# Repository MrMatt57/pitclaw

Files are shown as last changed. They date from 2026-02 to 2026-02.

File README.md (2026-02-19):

# Pit Claw logo Pit Claw



Open-source BBQ temperature monitor and controller. Uses an ESP32-S3 with a 3.5" touchscreen to maintain precise smoker temperature via PID-controlled fan and optional servo damper. Reads Thermoworks-compatible thermistor probes. Includes a web interface (PWA) for remote monitoring from any phone or computer on Wi-Fi. Touchscreen works fully offline.

### Touchscreen Dashboard

Real-time temperature display on the 3.5" capacitive touchscreen. Works fully offline — no Wi-Fi required.

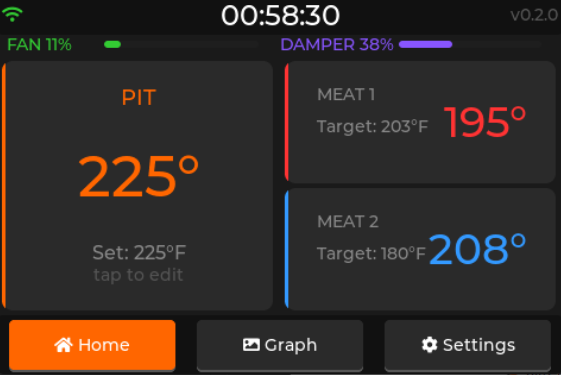
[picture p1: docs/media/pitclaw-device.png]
Pit Claw touchscreen dashboard


### Web Interface

Browser-based PWA with live temperature graph, predictive done-time curves, and full cook session control. Access from any device at `http://bbq.local`.

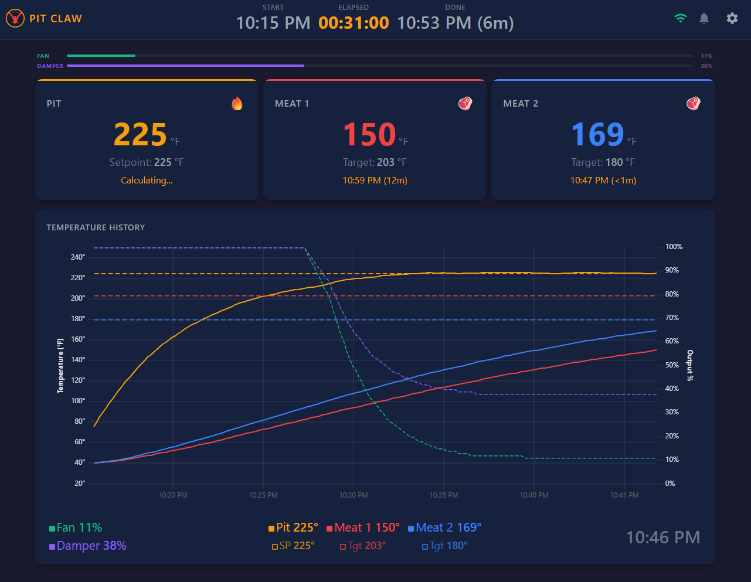
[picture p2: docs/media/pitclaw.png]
Pit Claw web UI with temperature history graph


## Features

- **3 probe inputs**: 1 pit (ambient) + 2 meat probes (Thermoworks Pro-Series compatible, 2.5mm jack)
- **PID temperature control**: Fan + optional damper hold pit temperature steady (±5°F typical)
- **3.5" capacitive touchscreen**: Real-time dashboard — works fully without Wi-Fi
- **Web UI (PWA)**: Install to home screen, real-time graph, set points, alarms, session export
- **Predictive curve**: Chart shows dashed projection from current meat temp to target with estimated done time
- **Alarms**: Local buzzer + browser audio + Pushover push notifications
- **Cook session logging**: Persists through power loss, download as CSV/JSON before starting next cook
- **Easy setup**: QR code on screen for Wi-Fi, captive portal, mDNS (`bbq.local`)
- **OTA updates**: Flash new firmware from the browser — no USB after initial setup
- **Error detection**: Probe disconnect/short, fire-out warning, Wi-Fi auto-reconnect
- **Calibration**: Per-probe Steinhart-Hart coefficients with offset adjustment
- **3D printable enclosure**: PETG case with snap-fit assembly

## Hardware

### Bill of Materials

All internal electronics mount on a single 50x70mm carrier perfboard behind the display. Requires basic soldering (~20 joints). Enclosure target is ~100x70x40mm.

| # | Component | Product | Qty | Price | Link |
|---|---|---|-----|---|---|
| 1 | MCU + Display | WT32-SC01 Plus (ESP32-S3, 3.5" 480x320 capacitive touch) | 1 | ~$20-25 | [Amazon](https://www.amazon.com/s?k=WT32-SC01+Plus) / AliExpress |
| 2 | ADC | ADS1115 16-bit I2C breakout (HiLetgo 3-pack) | 1 | ~$4 | [Amazon](https://www.amazon.com/s?k=ADS1115+16+bit) |
| 3 | Blower Fan | GDSTIME 5015 12V dual ball bearing blower (2-pack) | 1 | ~$10-12 | [Amazon](https://www.amazon.com/s?k=GDSTIME+5015+12V+blower) |
| 4 | MOSFET | IRLZ44N logic-level N-channel TO-220 (5-pack) | 1 | ~$7 | [Amazon](https://www.amazon.com/s?k=IRLZ44N+MOSFET) |
| 5 | Servo | Miuzei MG90S metal gear micro servo (2-pack) | 1 | ~$8-10 | [Amazon](https://www.amazon.com/s?k=MG90S+metal+gear+servo) |
| 6 | Power Supply | ALITOVE 12V 5A DC adapter (5.5x2.1mm barrel) | 1 | ~$10-12 | [Amazon](https://www.amazon.com/s?k=12V+5A+power+supply+barrel) |
| 7 | Buck Converter | MP1584EN mini adjustable DC-DC (6-pack, 22x17mm) | 1 | ~$8 | [Amazon](https://www.amazon.com/s?k=MP1584EN+buck+converter) |
| 8 | Power Jack | Panel-mount DC barrel jack 5.5x2.1mm (4-pack) | 1 | ~$6 | [Amazon](https://www.amazon.com/s?k=panel+mount+DC+barrel+jack+5.5x2.1) |
| 9 | Probe Jacks | CESS 2.5mm mono TS panel-mount with nut (4-pack) | 1 | ~$6-8 | [Amazon](https://www.amazon.com/s?k=2.5mm+mono+panel+mount+jack) |
| 10 | Buzzer | Piezo buzzer disc 3-5V (5-pack) | 1 | ~$5 | [Amazon](https://www.amazon.com/s?k=piezo+buzzer+disc+5V) |
| 11 | Carrier Board | 50x70mm perfboard (10-pack) | 1 | ~$6 | [Amazon](https://www.amazon.com/s?k=50x70mm+perfboard) |
| 12 | Resistors | 10K ohm 1% metal film (pack) | 3 | ~$5 | [Amazon](https://www.amazon.com/s?k=10K+1%25+metal+film+resistor) |
| 13 | Capacitors | 0.1uF ceramic (pack) | 3 | ~$5 | [Amazon](https://www.amazon.com/s?k=0.1uF+ceramic+capacitor) |
| 14 | Hookup Wire | 22AWG solid core (assorted colors) | 1 | ~$8 | [Amazon](https://www.amazon.com/s?k=22AWG+solid+core+hookup+wire) |
| | | **Total (excluding probes)** | | **~$95-115** | |

### Temperature Probes (buy separately)

Any Thermoworks Pro-Series probe with 2.5mm mono jack works:
- [TX-1003X-AP](https://www.thermoworks.com/tx-1003x-ap/) — Air/pit probe with grate clip (~$19)
- [TX-1001X-OP](https://www.thermoworks.com/tx-1001x-op/) — Cooking/meat probe (~$21)

Compatible alternatives: Maverick ET-72/73 replacement probes (different Steinhart-Hart coefficients), Inkbird, FireBoard probes.

### 3D Printed Parts

All parametric [OpenSCAD](https://openscad.org/) (free) source files in `enclosure/`. Pre-exported STLs in `enclosure/stl/` if you just want to print. See the [enclosure README](enclosure/README.md) for print settings and assembly instructions.

**Controller enclosure** (`bbq-case.scad`) — three parts:
- **Front bezel** — holds display, bezel lip frames the screen
- **Rear shell** — houses carrier board, panel-mount jacks, cable slots, ventilation
- **Kickstand** — detachable flip-out stand
- Target size: ~100 x 70 x 40mm
- Assembly: 4x M3x8mm screws

**Fan + damper assembly** (`bbq-fan-assembly.scad`) — two parts:
- **Blower housing** — holds 5015 fan, MG90S servo, butterfly damper plate
- **UDS pipe adapter** — friction-fits over 3/4" NPT pipe nipple, secured with hose clamp
- Airflow: outside air → damper → fan → duct → pipe adapter → drum
- The blower housing output is a standard round duct — future adapters for other smokers (WSM, kamado, offset) mate to the same interface

**Print settings** (both):
- Material: PETG (80°C glass transition, resists outdoor heat and grease)
- 4 walls, 30%+ infill, 0.2mm layers, no supports needed

**Additional hardware for assembly:**
- 4x M3x8mm screws + threaded inserts (controller case)
- 2x small hose clamps (fan assembly to pipe, adapter to pipe nipple)
- High-temp gasket tape (seal adapter to pipe nipple)

## Getting Started

### 1. Clone and Set Up

```bash
git clone https://github.com/MrMatt57/pitclaw.git
cd pitclaw
```

**Windows** — one script installs everything (Git, Python, PlatformIO CLI, OpenSCAD):

```powershell
# Run from an elevated (Admin) PowerShell
powershell -ExecutionPolicy Bypass -File scripts\setup-dev.ps1
```

**Other platforms** — install [PlatformIO CLI](https://docs.platformio.org/en/latest/core/installation.html) (`pip install platformio`).

### 2. Wire and Assemble

Solder the carrier board and wire everything up. See the [wiring guide](docs/wiring.md) for the full diagram and pin assignments.

### 3. Build and Flash

```bash
cd firmware

# Build firmware
pio run -e wt32_sc01_plus

# Connect WT32-SC01 Plus via USB-C, then flash
pio run -e wt32_sc01_plus --target upload

# Upload web UI files to flash filesystem
pio run -e wt32_sc01_plus --target uploadfs
```

After this initial flash, all future firmware updates can be done over Wi-Fi at `http://bbq.local/update`.

### 4. First Boot

1. Power on — the setup wizard starts on the touchscreen
2. Select temperature units (°F or °C)
3. Scan the QR code on screen with your phone to connect to the setup Wi-Fi
4. Enter your home Wi-Fi credentials in the portal page
5. Plug in probes — the wizard verifies live readings
6. Fan, servo, and buzzer do a quick self-test
7. Setup complete — dashboard appears

### 5. Use the Web UI

Open `http://bbq.local` in any browser on the same Wi-Fi network.

For the best experience, add it to your phone's home screen (it's a PWA):
- **iOS**: Safari → Share → Add to Home Screen
- **Android**: Chrome → Menu → Add to Home Screen

### Factory Reset

Hold your finger on the touchscreen for 10 seconds during the boot splash screen.

## Development

| Guide | Topics |
|---|---|
| [Firmware Development](docs/firmware-development.md) | Building, flashing, testing, architecture, configuration |
| [Web UI Development](docs/web-development.md) | Simulator, web UI editing, cook profiles, WebSocket protocol |
| [Wiring](docs/wiring.md) | Wiring diagram, pin assignments, carrier board layout |
| [Enclosure](enclosure/README.md) | 3D printing, assembly instructions, parametric customization |

## License

TBD

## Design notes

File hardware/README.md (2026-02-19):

# Hardware - KiCad Schematic

KiCad 8 project for the Pit Claw BBQ Controller carrier board circuit.

## Opening

1. Install [KiCad](https://www.kicad.org/) (free, open source)
2. Open `bbq-controller.kicad_pro`
3. The schematic editor opens `bbq-controller.kicad_sch`

## What's in the schematic

All components on the 50x70mm carrier board and their connections to the WT32-SC01 Plus:

| Ref | Component | Function |
|-----|---|---|
| U1 | MP1584EN module | 12V to 5V buck converter |
| U2 | ADS1115 module | 16-bit I2C ADC (3 probe channels) |
| Q1 | IRLZ44N | N-channel MOSFET fan driver |
| R1-R3 | 10K 1% | Probe voltage divider reference resistors |
| R4 | 10K | MOSFET gate pulldown |
| C1-C3 | 0.1uF | ADC input filter capacitors |
| BZ1 | Piezo buzzer | Audio alarm |
| J1 | Barrel jack | 12V DC power input |
| J2-J4 | 2.5mm mono jacks | Temperature probe connectors |
| J5 | 8-pin header | WT32-SC01 Plus extension connector |
| J6 | 3-pin header | MG90S servo (damper) |
| J7 | 2-pin header | 5015 blower fan |

## Net labels

Inter-section connections use net labels (matching labels are electrically connected):

| Net Label | Signal | From | To |
|---|---|---|-----|
| SDA | I2C data | U2 pin 3 | J5 pin 1 (GPIO10) |
| SCL | I2C clock | U2 pin 4 | J5 pin 2 (GPIO11) |
| FAN_PWM | Fan speed | Q1 gate / R4 | J5 pin 3 (GPIO12) |
| SERVO_SIG | Servo position | J6 pin 1 | J5 pin 4 (GPIO13) |
| BUZZER_SIG | Buzzer drive | BZ1 pin 1 | J5 pin 5 (GPIO14) |
| PROBE_PIT | Pit temp | R1/C1/J2 junction | U2 A0 (pin 7) |
| PROBE_MEAT1 | Meat 1 temp | R2/C2/J3 junction | U2 A1 (pin 8) |
| PROBE_MEAT2 | Meat 2 temp | R3/C3/J4 junction | U2 A2 (pin 9) |

## Exporting a viewable schematic

From KiCad's schematic editor:
- **PDF**: File > Export > PDF
- **SVG**: File > Export > SVG
- Place the exported file in `docs/` for easy reference

## Regenerating the schematic

The schematic is generated by `generate_schematic.py`. This script computes exact pin positions and wire endpoints so all connections are guaranteed to align.

```bash
python hardware/generate_schematic.py
```

To modify the schematic layout, edit component positions in the script and re-run. The script validates net label pairs on output.

## Notes

- Custom symbols (prefixed `bbq:`) are embedded in the schematic file -- no external symbol libraries needed
- The schematic uses standard KiCad power symbols (+12V, +5V, +3V3, GND)
- All wire endpoints are computed from pin definitions -- every connection is verified
- This is a carrier board schematic, not a PCB layout -- the board is hand-wired on perfboard

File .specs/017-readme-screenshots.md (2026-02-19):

# 017: Update README Screenshots

**Branch**: `feature/readme-screenshots`
**Created**: 2026-02-18

## Summary

Update the README to showcase both the hardware device and the web UI. Add a second screenshot for the embedded touchscreen device and update the existing web UI screenshot reference.

## Requirements

- Add a hardware/device screenshot placeholder in `docs/media/` (filename: `pitclaw-device.png`)
- Keep the existing web UI screenshot (`docs/media/pitclaw.png`) — user will replace the file with an updated version
- Update `README.md` to display both screenshots prominently near the top

## Design

Update the hero section of the README (after the badges, before Features) to show two screenshots side by side or stacked:
1. Hardware device photo (`pitclaw-device.png`) — placeholder file for now
2. Web UI screenshot (`pitclaw.png`) — existing file, user will update the actual image

Use a simple markdown table or inline images to display both.

## Files to Modify

| File | Change |
|---|---|
| `README.md` | Update screenshot section to show both device and web UI images |

## Test Plan

- [x] README renders correctly on GitHub with both image references
- [x] Placeholder filename `pitclaw-device.png` is referenced correctly
- [x] Existing `pitclaw.png` reference is preserved

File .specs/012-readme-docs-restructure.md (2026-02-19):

# 012: Restructure README and Documentation

**Branch**: `feature/readme-docs-restructure`
**Created**: 2026-02-18

## Summary

Restructure the README to focus on what new visitors need (what it is, hardware, quick start) and move developer-focused content into dedicated docs. The goal is a concise onboarding experience for people who want to build this project, with an index linking to deeper development guides.

## Requirements

- README should prominently show: what the project is, hardware requirements/BOM, and a quick getting started guide
- Move wiring diagram out of README into `docs/wiring.md`, linked from the hardware section
- Create `docs/firmware-development.md` covering firmware building, testing, architecture, and source layout
- Create `docs/web-development.md` covering simulator usage, cook profiles, web UI development, and WebSocket protocol
- README should have a "Development" section that serves as an index linking to the doc files
- Keep the README hardware section (BOM, probes, 3D printed parts) intact — builders need it
- Preserve all existing content; nothing should be lost, just reorganized
- All internal links should work correctly

## Design

### README.md (streamlined)

Keep these sections in README:
1. **Header** — logo, badge, one-paragraph description, screenshot
2. **Features** — bullet list (as-is)
3. **Hardware** — BOM table, probes, 3D printed parts. Add a link to `docs/wiring.md` for wiring details
4. **Quick Start** — condensed: clone, setup script, build & flash, first boot steps, accessing web UI, factory reset, OTA mention
5. **Development** — brief index paragraph linking to:
   - `docs/firmware-development.md` — building, testing, architecture
   - `docs/web-development.md` — web UI, simulator, WebSocket protocol
   - `docs/wiring.md` — wiring diagram and pin assignments
   - `enclosure/README.md` — 3D printing and assembly
6. **License** — TBD

Remove from README (moved to docs):
- Wiring diagram → `docs/wiring.md`
- Simulator section → `docs/web-development.md`
- Running Tests section → `docs/firmware-development.md`
- Web UI detailed description → `docs/web-development.md`

### docs/wiring.md

- Carrier board wiring diagram (the ASCII art from current README)
- Pin assignment table
- Probe voltage divider schematic

### docs/firmware-development.md

- Prerequisites (manual install list — the non-Windows path)
- Quick setup script mention
- Build & flash commands (firmware targets)
- Running tests (native + embedded)
- OTA update details
- Architecture overview: source layout tree, key modules described
- Configuration persistence (config.json structure)
- Error detection table
- Key technical constants (Steinhart-Hart, PID defaults, fan control)

### docs/web-development.md

- Simulator setup and usage (build, run, options)
- Cook profiles table
- Web UI features overview
- PWA details (manifest, service worker)
- WebSocket protocol documentation (all message types)
- Key constraint: web UI must work identically on simulator and ESP32
- Editing workflow (edit files in firmware/data/, refresh browser)

## Files to Modify

| File | Change |
|---|---|
| `README.md` | Restructure: keep intro/features/hardware/quick-start, add dev index, remove moved sections |
| `docs/wiring.md` | **New**: wiring diagram, pin assignments from README |
| `docs/firmware-development.md` | **New**: firmware dev guide with build/test/architecture content |
| `docs/web-development.md` | **New**: web UI + simulator dev guide |

## Test Plan

- [x] All links in README resolve correctly (relative paths to docs/)
- [x] No content lost — all information from old README exists somewhere in new structure
- [x] README is concise and focuses on builder onboarding
- [x] docs/wiring.md contains the full wiring diagram
- [x] docs/firmware-development.md covers building, testing, and architecture
- [x] docs/web-development.md covers simulator, web UI, and WebSocket protocol
- [ ] Firmware builds (`pio run -e wt32_sc01_plus`) — docs-only change, no source code modified
- [ ] Simulator builds (`pio run -e simulator`) — docs-only change, no source code modified

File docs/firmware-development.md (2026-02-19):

# Firmware Development

Guide for building, flashing, testing, and understanding the Pit Claw firmware.

## Prerequisites

### Quick Setup (Windows)

```powershell
# Run from an elevated (Admin) PowerShell in the repo root
powershell -ExecutionPolicy Bypass -File scripts\setup-dev.ps1
```

This installs Git, Python, Node.js, PlatformIO CLI, and OpenSCAD. The script is idempotent — safe to run again anytime.

### Manual Install

If you prefer to install tools yourself (or you're not on Windows):

1. [Git](https://git-scm.com/)
2. [Python 3.12+](https://www.python.org/)
3. [PlatformIO CLI](https://docs.platformio.org/en/latest/core/installation.html) — `pip install platformio`
4. [VS Code](https://code.visualstudio.com/) + [PlatformIO extension](https://platformio.org/install/ide?install=vscode) (recommended)

## Build Commands

All commands run from the `firmware/` directory.

```bash
# Build firmware
pio run -e wt32_sc01_plus

# Flash firmware via USB
pio run -e wt32_sc01_plus --target upload

# Upload web UI files to LittleFS
pio run -e wt32_sc01_plus --target uploadfs

# Build simulator (desktop, no hardware needed)
pio run -e simulator

# Clean build artifacts
pio run --target clean

# Serial monitor
pio device monitor --baud 115200
```

## Testing

```bash
# Desktop unit tests (PID, prediction, alarms — no hardware)
pio test -e native

# Single test suite
pio test -e native --filter test_desktop/test_pid

# On-device integration tests (requires connected hardware)
pio test -e wt32_sc01_plus
```

Tests use the Unity framework with two environments:
- **`native`** — runs on desktop, tests pure logic (PID, prediction, alarms, fan logic, temperature conversion)
- **`wt32_sc01_plus`** — runs on device, tests hardware integration (ADC, fan PWM, servo, buzzer, I2C)

## OTA Updates

After the initial USB flash, firmware can be updated over Wi-Fi:

1. Open `http://bbq.local/update` in a browser
2. Upload the `.bin` file from `.pio/build/wt32_sc01_plus/firmware.bin`
3. The device reboots with the new firmware

The LittleFS partition (config, session data, web UI files) is preserved across firmware updates.

## Architecture

### Source Layout

```
firmware/
  src/
    main.cpp                    # Setup + main loop (Arduino setup/loop pattern)
    config.h                    # Pin assignments, constants, defaults
    config_manager.h/.cpp       # Load/save config.json on LittleFS
    wifi_manager.h/.cpp         # WiFiManager captive portal, mDNS, auto-reconnect
    ota_manager.h/.cpp          # Web-based OTA firmware update endpoint
    pid_controller.h/.cpp       # PID wrapper (QuickPID + lid-open, startup, split-range)
    temp_manager.h/.cpp         # ADS1115 reading, Steinhart-Hart, EMA filtering
    temp_predictor.h/.cpp       # Rolling linear regression for done-time prediction
    fan_controller.h/.cpp       # PWM output with kick-start, long-pulse, min-speed
    servo_controller.h/.cpp     # Damper servo control
    alarm_manager.h/.cpp        # Threshold logic, hysteresis, buzzer + web triggers
    cook_session.h/.cpp         # Session state, circular buffer, LittleFS persistence
    error_manager.h/.cpp        # Probe disconnect/short, fan stall, fire-out detection
    web_protocol.h/.cpp         # Shared WebSocket protocol (message building/parsing)
    web_server.h/.cpp           # ESPAsyncWebServer, REST + WebSocket handlers
    split_range.h               # Fan + damper coordination from PID output
    units.h                     # Temperature unit conversion utilities
    display/
      ui_init.h/.cpp            # LVGL screen setup (dashboard, graph, settings)
      ui_update.h/.cpp          # Real-time widget updates
      ui_setup_wizard.h/.cpp    # First-boot setup wizard screens
      ui_colors.h               # Shared LVGL color constants
      graph_history.h/.cpp      # Adaptive-condensing graph history buffer
    simulator/                  # Desktop simulator (see web-development.md)
      sim_main.cpp              # SDL2 + mongoose main loop
      sim_thermal.h/.cpp        # Charcoal smoker physics simulation
      sim_profiles.h            # Pre-built cook profiles
      sim_web_server.h/.cpp     # Mongoose HTTP + WebSocket server
      mongoose.h/.c             # Mongoose embedded web server library
  data/                         # Web UI files (uploaded to LittleFS)
  test/
    test_desktop/               # Native tests
    test_embedded/              # On-device tests
  platformio.ini
```

### Key Modules

**PID Controller** (`pid_controller.h/.cpp`) — wraps QuickPID with BBQ-specific features: proportional-on-measurement, derivative-on-measurement, integral anti-windup conditioning. Includes lid-open detection (6% drop below setpoint) and startup mode.

**Temperature Manager** (`temp_manager.h/.cpp`) — reads ADS1115 ADC via I2C, converts raw ADC counts to temperature using Steinhart-Hart equation, applies EMA (exponential moving average) filtering, and supports per-probe calibration offsets.

**Fan + Damper Split-Range** (`split_range.h`) — the PID produces a single 0-100% output mapped to both actuators:
- Damper: linearly maps full PID range (0% = closed, 100% = open)
- Fan: activates above configurable threshold (default 30%), scales within its own min-max range
- Three modes: fan-only, fan+damper coordinated, damper-primary with fan boost

**Cook Session** (`cook_session.h/.cpp`) — stores the current cook as a circular buffer in RAM (600 samples, ~50 min at 5s intervals), flushed to LittleFS every 60 seconds for power-loss recovery. Only one session stored on device — web UI provides CSV/JSON download.

**Error Manager** (`error_manager.h/.cpp`) — detects probe disconnect (ADC max/open circuit), probe short (ADC zero), fire-out (pit declining >2°F/min for 10+ min at full fan), and Wi-Fi loss.

### Configuration

All user settings stored in `config.json` on LittleFS. Survives reboots and firmware OTA updates.

```json
{
  "wifi": { "ssid": "", "password": "" },
  "units": "F",
  "pid": { "p": 4.0, "i": 0.02, "d": 5.0 },
  "fan": { "mode": "fan_and_damper", "minSpeed": 15, "fanOnThreshold": 30 },
  "probes": {
    "pit":   { "name": "Pit",    "a": 7.3431401e-04, "b": 2.1574370e-04, "c": 9.5156860e-08, "offset": 0.0 },
    "meat1": { "name": "Meat 1", "a": 7.3431401e-04, "b": 2.1574370e-04, "c": 9.5156860e-08, "offset": 0.0 },
    "meat2": { "name": "Meat 2", "a": 7.3431401e-04, "b": 2.1574370e-04, "c": 9.5156860e-08, "offset": 0.0 }
  },
  "alarms": {
    "pitBand": 15,
    "pushover": { "enabled": false, "userKey": "", "apiToken": "" }
  },
  "setupComplete": false
}
```

### Technical Constants

**Thermoworks Pro-Series Steinhart-Hart Coefficients:**
- A = 7.3431401e-04, B = 2.1574370e-04, C = 9.5156860e-08
- Reference resistor: 10K ohm (1% metal film)
- 0.1uF ceramic filter cap on each ADC input

**PID Defaults (HeaterMeter-derived):**
- P = 4.0, I = 0.02, D = 5.0
- Temp sampling: 1s interval, 4-reading average
- PID compute: every 4 seconds
- Lid-open threshold: 6% drop below setpoint

**Fan Control:**
- PWM frequency: 25 kHz
- Kick-start: 75% for 500ms
- Long-pulse mode below 10% (10s cycle)
- Min sustained speed: 15%

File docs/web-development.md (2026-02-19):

# Web UI Development

Guide for developing the Pit Claw web interface and using the desktop simulator.

## Simulator

The simulator runs the LVGL touchscreen UI in an SDL2 window and serves the web UI via an embedded web server — no ESP32 hardware needed.

### Build and Run

```bash
cd firmware

# Build
pio run -e simulator

# Run (opens SDL2 window + web server at http://localhost:3000)
.pio/build/simulator/program
```

### Command-Line Options

```bash
.pio/build/simulator/program --speed 10         # 10x time acceleration
.pio/build/simulator/program --speed 50         # 50x speed (12-hour cook in ~15 min)
.pio/build/simulator/program --profile stall    # brisket stall scenario
.pio/build/simulator/program --port 8080        # custom web server port
```

### Cook Profiles

| Profile | Description | Duration (real time at 1x) |
|---|---|---|
| `normal` | 225°F pit, pork butt to 203°F, smooth rise | ~10 hours |
| `stall` | 225°F pit, brisket with 150-170°F stall plateau | ~14 hours |
| `hot-fast` | 300°F pit, chicken thighs to 185°F | ~2 hours |
| `temp-change` | Start at 225°F, bump to 275°F mid-cook | ~8 hours |
| `lid-open` | Normal cook with periodic lid-open temp drops | ~10 hours |
| `fire-out` | Normal cook, fire dies at 4 hours | ~6 hours |
| `probe-disconnect` | Normal cook, meat1 probe disconnects at 3 hours | ~10 hours |

### How It Works

- **SDL2 window** renders the LVGL touchscreen UI (same code as firmware)
- **Mongoose HTTP server** serves web UI files from `firmware/data/`
- **WebSocket** on the same port sends simulated data using the shared protocol (`web_protocol.cpp`)
- **Thermal model** (`sim_thermal.cpp`) simulates charcoal fire physics, heat decay, meat temp rise, and PID response

Both the touchscreen and web UI are driven by the same thermal model and shared WebSocket protocol — one source of truth.

### Editing the Web UI

Web UI files live in `firmware/data/`:

```
firmware/data/
  index.html          # Main page
  app.js              # Application logic
  style.css           # Styles
  manifest.json       # PWA manifest
  favicon.svg         # App icon
  sw.js               # Service worker (offline shell caching)
```

Edit these files and refresh your browser — no recompile needed. Only the simulator itself (C++ code) requires rebuilding.

**Key constraint:** The web UI code must work identically on both the simulator and the real ESP32. No simulator-specific code in the web UI — the abstraction boundary is the WebSocket protocol.

## Web UI Features

- **Live temperatures** — pit and both meat probes with set points
- **Temperature graph** — uPlot time-series chart with pit temp, meat temps, fan %, and damper %
- **Predictive curve** — dashed projection from current meat temp to target, with predicted done time
- **Controls** — set pit target temperature, meat target temperatures, alarm thresholds
- **Cook timer** — starts when pit reaches set point; tracks total cook time
- **Session export** — download cook data as CSV/JSON (device stores only current/last session)
- **OTA update** — flash new firmware at Settings → Update
- **Alarms** — configure pit deviation band, meat targets, Pushover notifications

### Graph

The timeline focuses on the active cook — ramp-up time is shown compressed on the left, with the main view starting from when the pit first reaches set temperature. The chart extends to the right with a dashed predictive curve showing the projected path to the meat target temperature, with the predicted done time displayed at the end. All times shown in the browser's local timezone.

### PWA

The web UI is a Progressive Web App:

- `manifest.json` defines the app name, icon, theme color, and `display: standalone`
- `sw.js` caches the app shell (HTML/JS/CSS) for offline loading — data still requires a WebSocket connection
- "Add to Home Screen" for a native-app experience on phones:
  - **iOS**: Safari → Share → Add to Home Screen
  - **Android**: Chrome → Menu → Add to Home Screen

## WebSocket Protocol

All communication between the web UI and device (or simulator) uses JSON over WebSocket.

### Server → Client

**Periodic data** (every 1-2 seconds):
```json
{
  "type": "data",
  "ts": 1707600000,
  "pit": 225.5,
  "meat1": 145.2,
  "meat2": 98.7,
  "fan": 45,
  "damper": 80,
  "sp": 225,
  "lid": false,
  "est": 1707614400,
  "meat1Target": 203,
  "meat2Target": null,
  "errors": []
}
```

**History dump** (on connect):
```json
{
  "type": "history",
  "sp": 225,
  "meat1Target": 203,
  "meat2Target": null,
  "data": [[ts, pit, meat1, meat2, fan, damper], ...]
}
```

**Session events:**
```json
{"type": "session", "action": "reset", "sp": 225}
{"type": "session", "action": "download", "format": "csv", "data": "timestamp,pit,meat1,...\n..."}
```

### Client → Server

```json
{"type": "set", "sp": 250}
{"type": "alarm", "meat1Target": 203, "meat2Target": 185, "pitBand": 15}
{"type": "session", "action": "new"}
{"type": "session", "action": "download", "format": "csv"}
```

### Timestamps

All timestamps from the ESP32 are UTC epoch seconds. The browser converts to local timezone for display. The chart library (uPlot) handles timezone-aware axis labels.

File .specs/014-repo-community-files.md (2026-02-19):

# 014: Repo Community Files

**Branch**: `feature/repo-community-files`
**Created**: 2026-02-18

## Summary

Add GitHub community files: Dependabot config, issue templates (bug report + feature request), PR template, and security policy. These were generated by the `/setup` command and need to be committed to the repo.

## Requirements

- Add `.github/dependabot.yml` — weekly updates for GitHub Actions and PlatformIO/pip
- Add `.github/ISSUE_TEMPLATE/bug_report.yml` — YAML form with description, repro steps, expected behavior, component dropdown, firmware version
- Add `.github/ISSUE_TEMPLATE/feature_request.yml` — YAML form with problem, proposed solution, alternatives, component dropdown
- Add `.github/ISSUE_TEMPLATE/config.yml` — disable blank issues
- Add `.github/PULL_REQUEST_TEMPLATE.md` — Summary + Test plan format matching /ship workflow
- Add `SECURITY.md` — responsible disclosure policy scoped to local-network IoT device

## Design

Straightforward file addition — all files already created by `/setup` command. Just need to be committed and pushed.

## Files to Modify

| File | Change |
|---|---|
| `.github/dependabot.yml` | Add — Dependabot config |
| `.github/ISSUE_TEMPLATE/bug_report.yml` | Add — Bug report template |
| `.github/ISSUE_TEMPLATE/feature_request.yml` | Add — Feature request template |
| `.github/ISSUE_TEMPLATE/config.yml` | Add — Disable blank issues |
| `.github/PULL_REQUEST_TEMPLATE.md` | Add — PR template |
| `SECURITY.md` | Add — Security policy |

## Test Plan

- [x] All 6 files exist with correct content
- [x] Issue templates use valid GitHub YAML form syntax
- [x] Dependabot config uses v2 format
- [x] PR template matches /ship workflow format (Summary + Test plan)
- [x] SECURITY.md links to correct repo for private vulnerability reporting

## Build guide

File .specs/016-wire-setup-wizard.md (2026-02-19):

# 016: Wire Setup Wizard into Boot Flow + Boot Splash

**Branch**: `feature/wire-setup-wizard`
**Created**: 2026-02-18

## Summary

The setup wizard UI is fully implemented (all 6 steps: Welcome, Units, Wi-Fi QR, Probe Check, Hardware Test, Done) but nothing in `main.cpp` or `sim_main.cpp` calls it. This feature wires the wizard into the boot flow so it runs on first boot (when `setupComplete == false`), adds a boot splash screen with a 10-second hold for factory reset, and adds a `--wizard` CLI flag to the simulator for testing the wizard flow in the SDL2 window.

## Requirements

- On startup, show a boot splash screen for 2 seconds with "Pit Claw" branding and version
- During boot splash, if user holds the touchscreen for 10 continuous seconds, trigger factory reset (wipe config, restart into wizard)
- Show a progress indicator during the hold so the user knows it's working
- After boot splash, check `configManager.isSetupComplete()`:
  - If `false` → launch the setup wizard
  - If `true` → load the dashboard (current behavior)
- Wire all wizard callbacks in `main.cpp`: units selection saves to configManager, hardware test buttons trigger fan/servo/buzzer, completion sets `setupComplete = true` and saves config
- After wizard's Done screen, automatically transition to the dashboard after a brief pause (2 seconds)
- During wizard, update probe readings on the probe-check screen from `tempManager` in the main loop
- Simulator: add `--wizard` flag to force-start the wizard (simulates first-boot)
- Simulator: wire wizard callbacks with simulator-local stubs (print messages for hardware test, update `g_is_fahrenheit` for units)
- Simulator: boot splash shown briefly (1 second) when `--wizard` is used, skipped otherwise

## Design

### Boot Splash Screen (`ui_boot_splash.h/.cpp`)

New LVGL module with a simple splash screen:
- Dark background (`COLOR_BG`)
- "Pit Claw" in large orange text centered
- Version string below in dim text
- Small hint at bottom: "Hold screen 10s for factory reset" in very dim text
- A thin progress bar (hidden by default) that fills over 10 seconds when the screen is pressed

Public API:
```cpp
void ui_boot_splash_init();                    // Create and show splash screen
bool ui_boot_splash_is_active();               // Still in splash phase?
void ui_boot_splash_update(bool pressed);      // Call each loop tick with touch state
bool ui_boot_splash_factory_reset_triggered(); // Was 10s hold completed?
float ui_boot_splash_hold_progress();          // 0.0-1.0 for progress bar
void ui_boot_splash_end();                     // Clean up splash, prepare for next screen
```

The splash screen handles its own timing internally:
- Tracks cumulative press duration (resets if released)
- After 2 seconds with no press, marks itself as done (`is_active` → false)
- If press reaches 10 seconds, sets factory_reset flag and marks done
- The 2-second auto-dismiss timer pauses while the screen is being pressed

### Main.cpp Boot Flow Changes

Add a boot phase state machine:
```cpp
enum class BootPhase { SPLASH, WIZARD, RUNNING };
static BootPhase g_bootPhase = BootPhase::SPLASH;
```

In `setup()`:
1. Init all hardware modules as today (steps 1-12 unchanged)
2. Call `ui_init()` (initializes LVGL, creates no screens yet — we'll show splash first)
3. Call `ui_boot_splash_init()` to show the splash screen
4. Do NOT set up dashboard callbacks yet

In `loop()`:
- **SPLASH phase**: Only run `ui_tick()` + `ui_handler()` + `ui_boot_splash_update()`. Check `ui_boot_splash_is_active()`. When done:
  - If factory reset triggered → call `configManager.factoryReset()` (which restarts)
  - If `!configManager.isSetupComplete()` → init wizard, wire wizard callbacks, switch to WIZARD phase
  - Else → init dashboard, wire dashboard callbacks, switch to RUNNING phase
- **WIZARD phase**: Run `ui_tick()` + `ui_handler()`. Update wizard probe readings at 1Hz. When `!ui_wizard_is_active()`:
  - Init dashboard, wire dashboard callbacks, switch to RUNNING phase
- **RUNNING phase**: Existing loop behavior (all module updates, display updates, etc.)

### Wizard Callbacks in main.cpp

```cpp
static void wiz_fan_test() {
    fanController.setSpeed(75);
    delay(500);
    fanController.setSpeed(0);
}
static void wiz_servo_test() {
    servoController.setPosition(100);
    delay(500);
    servoController.setPosition(0);
}
static void wiz_buzzer_test() {
    alarmManager.beepOnce();  // Need to verify this method exists, or use direct buzzer
}
static void wiz_units(bool isFahrenheit) {
    configManager.setUnits(isFahrenheit ? "F" : "C");
    tempManager.setUseFahrenheit(isFahrenheit);
}
static void wiz_complete() {
    configManager.setSetupComplete(true);
    configManager.save();
}
```

### Wizard → Dashboard Transition

After the wizard's Done screen (step 5), `cb_complete` fires immediately. But we want the "Setup Complete!" screen to show for ~2 seconds before transitioning to the dashboard. Two approaches:

**Chosen approach**: In the WIZARD phase of the main loop, after `ui_wizard_is_active()` returns false, start a 2-second timer. After the timer expires, initialize the dashboard and switch to RUNNING. This keeps the transition logic in main.cpp rather than in the wizard module.

### Simulator Changes (`sim_main.cpp`)

Add `--wizard` CLI flag:
```cpp
bool wizardMode = false;
// In arg parsing:
} else if (strcmp(argv[i], "--wizard") == 0) {
    wizardMode = true;
}
```

When `wizardMode` is true:
1. Show boot splash briefly (1 second delay with LVGL ticking)
2. Call `ui_wizard_init()` and `ui_wizard_set_callbacks()` with simulator stubs
3. In main loop, check `ui_wizard_is_active()` — when done, init dashboard and continue

Simulator wizard callbacks:
- Fan test: `printf("[SIM] Fan test\n")`
- Servo test: `printf("[SIM] Servo test\n")`
- Buzzer test: `printf("[SIM] Buzzer test\n")`
- Units: Update `g_is_fahrenheit` and call `ui_set_units()`
- Complete: Print message, no config save needed

When `wizardMode` is false: skip splash, go straight to dashboard as today.

Update `print_usage()` to list `--wizard` option.

### Existing Wizard Module — No Changes Needed

The wizard code in `ui_setup_wizard.cpp` is complete and doesn't need modification. The `cb_complete` callback + `wizard_active = false` behavior gives main.cpp everything it needs to detect completion and transition.

### Build Filter

The simulator build already includes `+<display/>` which will pick up the new `ui_boot_splash.cpp`. No `platformio.ini` changes needed.

## Files to Modify

| File | Change |
|---|---|
| `firmware/src/display/ui_boot_splash.h` | **NEW** — Boot splash screen header |
| `firmware/src/display/ui_boot_splash.cpp` | **NEW** — Boot splash screen with hold-to-reset logic |
| `firmware/src/main.cpp` | Add boot phase state machine, wire wizard callbacks, splash → wizard → dashboard flow |
| `firmware/src/simulator/sim_main.cpp` | Add `--wizard` flag, boot splash, wizard callback stubs, wizard → dashboard transition |

## Test Plan

- [ ] Simulator builds (`pio run -e simulator`)
- [ ] Simulator runs normally (no --wizard): skips splash, shows dashboard immediately
- [ ] Simulator with `--wizard`: shows boot splash briefly, then setup wizard with all 6 steps
- [ ] Wizard units step: tapping °F or °C advances and prints unit choice
- [ ] Wizard hardware test: tapping Fan/Servo/Buzzer buttons prints test messages
- [ ] Wizard Done step: shows "Setup Complete!" then auto-transitions to dashboard after ~2s
- [ ] After wizard completes, dashboard is fully functional (thermal sim runs, web UI serves)
- [ ] Firmware builds (`pio run -e wt32_sc01_plus`)
- [ ] Desktop tests pass (`pio test -e native`)

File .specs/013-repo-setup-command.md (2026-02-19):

# 013: Repo Setup Command

**Branch**: `feature/repo-setup-command`
**Created**: 2026-02-18

## Summary

Create a `/setup` Claude Code slash command that configures the GitHub repo with best practices for a solo developer. It audits current settings, shows a summary of proposed changes, asks for confirmation, then executes all configuration via `gh` CLI and file creation. Designed to be run once per repo.

## Requirements

- Create `.claude/commands/setup.md` as a Claude Code slash command
- The command must:
  1. Audit current repo state (branch protection, settings, labels, templates, etc.)
  2. Display a clear summary of what will be changed/created
  3. Ask user for confirmation before making any changes
  4. Execute all changes via `gh` API calls and file creation
  5. Report what was done
- Solo-dev-friendly: no required PR reviews, no team-oriented friction
- Idempotent where possible (safe to re-run, skips things already configured)

## Design

The command is a Claude Code slash command (`.claude/commands/setup.md`) with allowed tools for `gh` API calls, file creation, and bash commands. It runs interactively — Claude audits, presents a plan, confirms, then executes.

### What it configures:

#### 1. Branch Protection (update `main`)
- **Required status checks**: keep existing (`Firmware Build & Test`), enable strict (up-to-date before merge)
- **Required PR reviews**: remove (set to 0) — solo dev, no reviewer
- **Required linear history**: enable — enforces squash/rebase (matches squash-only setting)
- **Force pushes**: keep blocked
- **Branch deletion**: keep blocked
- **Enforce admins**: keep false — allows admin bypass in emergencies

#### 2. Repo Settings
- **Topics**: `esp32`, `esp32-s3`, `bbq`, `temperature-controller`, `pid-controller`, `smoker`, `iot`, `arduino`, `lvgl`, `platformio`, `pwm`
- **Vulnerability alerts**: enable

#### 3. Dependabot (`.github/dependabot.yml`)
- GitHub Actions: weekly updates
- PlatformIO/pip: weekly updates (pip ecosystem for PlatformIO)

#### 4. Issue Templates
- `.github/ISSUE_TEMPLATE/bug_report.yml` — YAML form: description, steps to reproduce, expected behavior, environment (firmware version, browser, etc.)
- `.github/ISSUE_TEMPLATE/feature_request.yml` — YAML form: problem, proposed solution, alternatives considered
- `.github/ISSUE_TEMPLATE/config.yml` — disable blank issues, link to discussions if enabled

#### 5. PR Template
- `.github/PULL_REQUEST_TEMPLATE.md` — Summary (bullet points) + Test Plan (checklist) format matching the `/ship` workflow

#### 6. Security Policy
- `SECURITY.md` — responsible disclosure policy, supported versions, contact info

#### 7. Project Labels
Add these project-specific labels (keep existing defaults):
| Label | Color | Description |
|---|---|---|
| `firmware` | `#1d76db` | ESP32 firmware code |
| `web-ui` | `#0e8a16` | Web UI (PWA) |
| `touchscreen` | `#5319e7` | LVGL touchscreen UI |
| `simulator` | `#fbca04` | Desktop simulator |
| `enclosure` | `#b60205` | 3D printed enclosure/hardware design |
| `hardware` | `#e99695` | Hardware, wiring, carrier board |
| `pid` | `#f9d0c4` | PID controller and tuning |
| `ci-cd` | `#c5def5` | CI/CD pipeline and automation |

### Command Flow

```
/setup

Claude:
1. Runs gh api calls to audit current state
2. Checks which files already exist
3. Presents summary:
   "Here's what I'll set up for your repo:

   Branch Protection:
   ✓ Required CI checks (already set)
   → Remove required PR reviews (currently 1)
   → Enable linear history

   Repo Settings:
   → Add topics: esp32, bbq, ...
   → Enable vulnerability alerts

   Files to Create:
   → .github/dependabot.yml
   → .github/ISSUE_TEMPLATE/bug_report.yml
   → .github/ISSUE_TEMPLATE/feature_request.yml
   → .github/ISSUE_TEMPLATE/config.yml
   → .github/PULL_REQUEST_TEMPLATE.md
   → SECURITY.md

   Labels to Add:
   → firmware, web-ui, touchscreen, simulator, enclosure, hardware, pid, ci-cd

   Proceed?"
4. On confirmation, executes everything
5. Reports results
```

## Files to Modify

| File | Change |
|---|---|
| `.claude/commands/setup.md` | Create — the slash command definition |
| `.claude/settings.json` | May need to add `Skill(setup)` to permissions if needed |

## Files Created by the Command (when run)

These files are NOT created during implementation — they are created when the `/setup` command is executed by the user:

| File | Purpose |
|---|---|
| `.github/dependabot.yml` | Dependabot configuration |
| `.github/ISSUE_TEMPLATE/bug_report.yml` | Bug report template |
| `.github/ISSUE_TEMPLATE/feature_request.yml` | Feature request template |
| `.github/ISSUE_TEMPLATE/config.yml` | Issue template config |
| `.github/PULL_REQUEST_TEMPLATE.md` | PR template |
| `SECURITY.md` | Security policy |

## Test Plan

- [x] `.claude/commands/setup.md` exists and is well-formed
- [x] Command includes `allowed-tools` frontmatter with necessary permissions (`Bash(gh *)`, `Write`, `Read`, `Glob`, `AskUserQuestion`)
- [x] Command audits current repo state before proposing changes
- [x] Command shows a clear summary of all proposed changes
- [x] Command asks for user confirmation before executing
- [x] Command handles already-configured items gracefully (skip or note as "already set")
- [x] All `gh` API calls in the command use correct endpoints and payloads
- [x] File templates (issue, PR, security, dependabot) follow GitHub's expected format
- [x] Labels use valid hex colors
- [x] Command is documented as one-time-use

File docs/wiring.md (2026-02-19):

# Wiring

All components on the carrier perfboard are connected with short soldered traces. External connections use wire runs to panel-mount jacks and the display board.

## Wiring Diagram

```
Panel-mount DC barrel jack (12V in)
  │
  └─► Carrier Board 12V rail
       ├─► MP1584EN buck converter IN → OUT (set to 5.0V)
       │     ├─► WT32-SC01 Plus 5V (via extension cable)
       │     └─► Servo VCC
       │
       ├─► IRLZ44N MOSFET drain
       │     └─► Fan +12V (fan GND to MOSFET source)
       │         Gate ◄── GPIO12 (with 10K pulldown to GND)
       │
       └─► GND rail (common ground)

WT32-SC01 Plus Extension Connector (8-pin ribbon cable)
  GPIO10 (SDA) ──► ADS1115 SDA (on carrier board)
  GPIO11 (SCL) ──► ADS1115 SCL (on carrier board)
  GPIO12       ──► IRLZ44N gate (on carrier board)
  GPIO13       ──► Servo signal (wire to servo)
  GPIO14       ──► Buzzer (on carrier board)
  3.3V         ──► ADS1115 VDD + voltage divider supply
  5V           ──► From MP1584EN output
  GND          ──► Common ground rail

Probe voltage dividers (on carrier board, x3)
  3.3V ──[10K 1% resistor]──┬──► ADS1115 AINx
                             │
                       [0.1uF cap]
                             │
    Panel-mount 2.5mm jack ──┴──► GND
    (tip=signal, sleeve=GND, polarity doesn't matter)
```

## Pin Assignments

| GPIO | Function |
|---|---|
| 10 | I2C SDA (ADS1115) |
| 11 | I2C SCL (ADS1115) |
| 12 | Fan PWM (via MOSFET) |
| 13 | Servo PWM |
| 14 | Buzzer |
| 21 | Spare |

## Carrier Board Layout (50x70mm)

```
┌──────────────────────────────────────────────────┐
│  MP1584EN        ADS1115 (socketed)              │
│  buck conv       ┌─────────┐                     │
│  ┌──────┐        │ A0 A1 A2│ A3(spare)           │
│  │12V→5V│        └─────────┘                     │
│  └──────┘                                        │
│                  R1  R2  R3   (10K 1% resistors)  │
│  IRLZ44N        C1  C2  C3   (0.1uF caps)       │
│  ┌──┐  10K                                       │
│  │FET│  pulldown  [BUZZER]                       │
│  └──┘                                            │
│                                                  │
│  Connectors: [12V in] [Fan] [Servo] [WT32 ext]  │
│              [Probe1] [Probe2] [Probe3]          │
└──────────────────────────────────────────────────┘
```

Components on the carrier board (~20 solder joints total):
- MP1584EN mini buck converter (12V→5V, 22x17mm module)
- ADS1115 breakout (pin-header socketed for replacement)
- IRLZ44N MOSFET (TO-220, logic-level, fully on at 3.3V for <1A loads) + 10K gate pulldown resistor
- 3x 10K 1% metal film resistors (voltage dividers)
- 3x 0.1uF ceramic capacitors (ADC input filters)
- Piezo buzzer (soldered directly)
- Power distribution traces (12V, 5V, 3.3V, GND rails)

Connections off the carrier board (short wire runs):
- 8-pin ribbon to WT32-SC01 Plus extension connector (2.0mm pitch, cable included with board)
- Wire pairs to panel-mount 2.5mm probe jacks (soldered to jack lugs)
- Wire pair to panel-mount DC barrel jack
- 2-pin to fan (JST-XH or direct solder)
- 3-pin to servo (standard servo connector)

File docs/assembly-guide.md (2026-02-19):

# Pit Claw BBQ Controller - Assembly Guide

Step-by-step instructions for building the Pit Claw temperature controller carrier board, wiring it to the WT32-SC01 Plus display, and assembling the enclosure.

## Safety

- **Soldering iron**: Work in a ventilated area. The iron tip is 300-400C. Use a stand and keep the tip away from skin, clothing, and plastic.
- **Lead-free solder recommended**: Wash hands after soldering.
- **12V power**: The barrel jack input is low-voltage DC (12V, ~2A max). No mains voltage is involved, but avoid shorting 12V to 3.3V components.
- **ESD awareness**: The ESP32-S3 and ADS1115 are sensitive to static. Touch a grounded metal surface before handling bare PCBs.

## Tools Required

| Tool | Notes |
|---|---|
| Soldering iron (adjustable temp) | 300-350C for through-hole, 230C for heat-set inserts |
| Solder (0.8mm rosin core) | Lead-free recommended |
| Wire strippers | For 22-26 AWG hookup wire |
| Flush cutters | Trimming leads and wire |
| Multimeter | Voltage and continuity testing (essential) |
| Screwdrivers (Phillips #1, #0) | M3 and M2 screws |
| Helping hands / PCB holder | Makes perfboard work much easier |
| Heat-shrink tubing + heat gun | Insulating solder joints on wire runs |
| Hot glue gun (optional) | Strain relief for wires |
| 22-26 AWG stranded hookup wire | Red, black, and 2-3 signal colors. ~1m of each |

## Bill of Materials

### Carrier Board Components

| Ref | Qty | Component | Specs | Notes |
|-----|-----|---|---|---|
| U1 | 1 | MP1584EN buck converter module | 22x17mm, adj output | Set to 5.0V with trimpot before installing |
| U2 | 1 | ADS1115 breakout board | 16-bit I2C ADC | Socket it (use pin headers) for easy replacement |
| Q1 | 1 | IRLZ44N N-channel MOSFET | TO-220, logic-level | Fully on at 3.3V gate drive |
| R1-R3 | 3 | 10K resistor (1% metal film) | 1/4W, axial | Probe voltage dividers |
| R4 | 1 | 10K resistor | 1/4W, axial | MOSFET gate pulldown |
| C1-C3 | 3 | 0.1uF ceramic capacitor | Axial or radial | ADC input noise filters |
| BZ1 | 1 | Piezo buzzer | 5V passive or active | Soldered directly to board |
| - | 1 | 50x70mm perfboard | 2.54mm pitch, double-sided | The carrier board itself |
| - | 2 | Pin header strips (female) | 2.54mm, for ADS1115 socket | Cut to length for the ADS1115 breakout |
| - | 1 | 8-pin connector / header | 2.0mm pitch | Mates with WT32-SC01 Plus extension connector |

### Panel-Mount Connectors

| Qty | Component | Notes |
|-----|---|---|
| 3 | 2.5mm mono panel-mount jacks | Thermoworks probe connectors (tip + sleeve) |
| 1 | DC barrel jack (panel-mount) | 5.5x2.1mm, 12V input |

### External Components

| Qty | Component | Notes |
|-----|---|---|
| 1 | WT32-SC01 Plus | ESP32-S3 with 3.5" 480x320 capacitive touchscreen |
| 1 | 5015 12V blower fan | 50x50x15mm centrifugal blower |
| 1 | MG90S servo | Standard micro servo for damper control |
| 1-3 | Thermoworks Pro-Series probes | NTC thermistor, 2.5mm mono plug |
| 1 | 12V DC power supply | 2A minimum, barrel plug 5.5x2.1mm |
| 1 | 8-pin ribbon cable (2.0mm) | Included with WT32-SC01 Plus board |

### Enclosure Hardware

| Qty | Component | Notes |
|-----|---|---|
| 4 | M3x8mm screws | Join bezel to rear shell |
| 4 | M3 heat-set threaded inserts | Optional (screws self-tap into PETG) |
| 4 | M3x6mm screws | Mount WT32-SC01 Plus to bezel standoffs |
| 4 | M3x6mm screws | Mount carrier board to shell standoffs (optional) |

---

## Schematic

The full circuit schematic is in KiCad format: [`hardware/bbq-controller.kicad_sch`](../hardware/bbq-controller.kicad_sch)

**To view/edit:** Open the `.kicad_pro` file in [KiCad](https://www.kicad.org/) (free, open source, industry standard EDA). You can export to PDF or SVG from KiCad via File > Export.

The circuit has five functional sections:

1. **Power supply** - 12V barrel jack through MP1584EN buck converter to 5V rail
2. **Probe voltage dividers** - 3x identical circuits: 3.3V -> 10K resistor -> junction -> NTC probe -> GND, with 0.1uF filter cap at each junction
3. **ADS1115 ADC** - Reads the three probe voltage divider junctions on A0-A2, communicates to ESP32 via I2C
4. **Fan driver** - IRLZ44N MOSFET switches 12V to the blower fan, gate driven by GPIO12 PWM with 10K pulldown
5. **Servo & buzzer** - Direct GPIO connections (GPIO13 servo signal, GPIO14 buzzer)

### Simplified Circuit Diagram

```
                           3.3V (from WT32)
                             |
                     ┌───────┼───────┐
                     |       |       |
                   [10K]   [10K]   [10K]    R1, R2, R3
                     |       |       |
              ┌──────┤───────┤───────┤
              |      |       |       |
            [0.1uF] [0.1uF] [0.1uF]        C1, C2, C3
              |      |       |       |
             GND    GND     GND     |
                     |       |       |
                    NTC     NTC     NTC     Probe thermistors
                     |       |       |      (via 2.5mm jacks)
                    GND     GND     GND

              A0─────┘   A1─┘   A2──┘
              ┌──────────────────────┐
              |      ADS1115        |
              |   (I2C: 0x48)       |
              └──┬───────┬──────────┘
                SDA     SCL
                 |       |
              GPIO10  GPIO11        WT32-SC01 Plus

  12V ────┬──[MP1584EN]──── 5V ────── WT32 5V pin
          |                           Servo VCC
          |
          ├──── Fan (+)
          |       |
          |     Fan (-)
          |       |
          |    Drain
          |   ┌──┤ IRLZ44N (Q1)
          |   |  Gate──────── GPIO12
          |   |  |
          |  [10K] R4 (pulldown)
          |   |  |
          |  GND Source
          |       |
          └──────GND

  GPIO13 ──── Servo Signal (orange wire)
  GPIO14 ──── Buzzer (+)
  GND    ──── Buzzer (-), Servo GND (brown wire)
```

---

## Perfboard Layout

The carrier board is a **50x70mm perfboard** (2.54mm hole pitch). The layout below shows where each component goes on the **front** (component side) of the board. The grid uses column letters (A-S, left to right) and row numbers (1-27, top to bottom).

### Component Placement Map (Front View)

```
            50mm (19 columns)
     A  B  C  D  E  F  G  H  I  J  K  L  M  N  O  P  Q  R  S
     ┌──────────────────────────────────────────────────────────┐
  1  │  .  .  .  .  .  .  .  .  .  .  .  .  .  .  .  .  .  .  │
  2  │  .  .  .  .  .  .  .  .  .  .  .  .  .  .  .  .  .  .  │
  3  │  . ┌──────────────┐ .  .  .  .  .  .  .  .  .  .  .  . │
  4  │  . │  MP1584EN    │ .  .  .  .  .  .  .  .  .  .  .  . │  70mm
  5  │  . │  buck conv   │ .  .  .  .  .  .  .  .  .  .  .  . │  (27
  6  │  . │  U1          │ .  .  .  .  .  .  .  .  .  .  .  . │  rows)
  7  │  . └──IN+ IN- OUT+ OUT-  .  .  .  .  .  .  .  .  .  . │
  8  │  .  .  .  .  .  .  .  .  .  .  .  .  .  .  .  .  .  .  │
  9  │  .  .  .  .  .  .  .  .  . ┌──────────────────┐  .  .  │
 10  │  .  .  .  .  .  .  .  .  . │  ADS1115 breakout│  .  .  │
 11  │  .  .  .  .  .  .  .  .  . │  U2 (socketed)   │  .  .  │
 12  │  .  .  .  .  .  .  .  .  . │  VDD GND SDA SCL │  .  .  │
 13  │  .  .  .  .  .  .  .  .  . │  A0  A1  A2  A3  │  .  .  │
 14  │  .  .  .  .  .  .  .  .  . └──────────────────┘  .  .  │
 15  │  .  .  .  .  .  .  .  .  .  R1   R2   R3  .  .  .  .  │
 16  │  .  .  .  .  .  .  .  .  .  │    │    │   .  .  .  .  │
 17  │  .  .  .  .  .  .  .  .  .  C1   C2   C3  .  .  .  .  │
 18  │  Q1 ┌──┐ .  .  .  .  .  .  .  .  .  .  .  . [BZ1]  . │
 19  │  G──│FET│──D  .  .  .  .  .  .  .  .  .  .  . buzzer . │
 20  │  │  └──┘  │  .  .  .  .  .  .  .  .  .  .  .  .  .  . │
 21  │  R4  S    │  .  .  .  .  .  .  .  .  .  .  .  .  .  . │
 22  │  │   │    │  .  .  .  .  .  .  .  .  .  .  .  .  .  . │
 23  │  .  .  .  .  .  .  .  .  .  .  .  .  .  .  .  .  .  .  │
 24  │  12V FAN  FAN SVO SVO SVO  .  .  PRB1 PRB1 PRB2 PRB2 PRB3│
 25  │  (+) (+)  (-) SIG VCC GND .  .  TIP  SLV  TIP  SLV  TIP │
 26  │  GND .    .   .   .   .   .  .  .    .    .    .    SLV │
 27  │  . ── WT32 8-pin ribbon cable pads ──  .  .  .  .  .  . │
     └──────────────────────────────────────────────────────────┘
          ▲ BOTTOM EDGE (faces rear shell panel-mount holes) ▲
```

### Component Reference

| Grid Position | Component | Notes |
|---|---|---|
| B3-G7 | U1 (MP1584EN) | Module pins: B7=IN+, D7=IN-, E7=OUT+, G7=OUT- |
| J9-Q14 | U2 (ADS1115) | Socketed in female pin headers. Check your breakout's pinout! |
| J15-J17 | R1 + C1 | Pit probe divider (connects to ADS1115 A0) |
| L15-L17 | R2 + C2 | Meat 1 probe divider (connects to ADS1115 A1) |
| N15-N17 | R3 + C3 | Meat 2 probe divider (connects to ADS1115 A2) |
| A18-C22 | Q1 (IRLZ44N) | TO-220, A19=Gate, B18-B20=body, C19=Drain |
| A21-A22 | R4 (10K) | Gate pulldown: Gate to GND |
| P18-P19 | BZ1 (Buzzer) | (+) up toward GPIO14 pad, (-) down to GND |
| A24-A26 | 12V + GND | Barrel jack wires solder here |
| B24-C24 | Fan + / Fan - | Fan connector pads |
| D24-F24 | Servo | Signal, VCC (5V), GND pads |
| I24-S26 | Probe jacks | Tip and Sleeve wire pads for each jack |
| A27-H27 | WT32 ribbon | 8-pin pads for ribbon cable to WT32-SC01 Plus |

### Wiring on the Back (Solder Side)

All connections are made on the **back of the perfboard** using short wire jumpers or solder bridges. Here are the key traces to run:

**Power rails** (run these first):
1. **GND bus** — horizontal trace along row 23, connecting: U1 OUT-, Q1 Source, R4 bottom, all cap bottoms (C1-C3), buzzer (-), all probe jack sleeves, J5 pin 8
2. **12V trace** — from barrel jack pad (A24) to U1 IN+ (B7), and to fan (+) pad (B24)
3. **5V trace** — from U1 OUT+ (E7) to servo VCC pad (E24), and to J5 pin 7
4. **3.3V bus** — from J5 pin 6 to: top of R1 (J15), top of R2 (L15), top of R3 (N15), and ADS1115 VDD

**Signal traces:**
5. **Probe junctions** — bottom of R1/top of C1 → ADS1115 A0, and → Probe 1 tip pad. Same for R2→A1→Probe 2, R3→A2→Probe 3
6. **I2C** — ADS1115 SDA → J5 pin 1 (GPIO10). ADS1115 SCL → J5 pin 2 (GPIO11)
7. **Fan PWM** — J5 pin 3 (GPIO12) → Q1 Gate (A19). Also R4 from Gate to GND
8. **Servo signal** — J5 pin 4 (GPIO13) → Servo signal pad (D24)
9. **Buzzer signal** — J5 pin 5 (GPIO14) → Buzzer (+) pad (P18)
10. **ADS1115 ADDR** — ADS1115 ADDR pin → GND bus (sets I2C address 0x48)

> Photo placeholder
> *Photo: Perfboard with components laid out before soldering (dry fit)*

> Photo placeholder
> *Photo: Back of perfboard showing all solder traces and wire jumpers*

### Tips for Perfboard Wiring

- **Plan before soldering.** Lay out all components in their positions first (dry fit). Use the grid map above as reference.
- **Solder power rails first.** GND bus → 12V → 5V → 3.3V. Test each rail before moving to signals.
- **Use colored wire.** Red for power, black for GND, and distinct colors for signal traces (e.g., blue for I2C, green for PWM).
- **Keep traces short.** Route wires on the back side along rows/columns. Avoid diagonal runs.
- **Socket the ADS1115.** Use female pin headers so you can remove the breakout board for debugging or replacement.
- **Check orientation.** MOSFET Q1 has Gate-Drain-Source left to right when facing the label. Verify your specific ADS1115 breakout's pinout — they vary between manufacturers.
- **Test as you go.** After each phase, use a multimeter to verify connections match the wiring list above.

---

## Assembly Instructions

### Overview

The build has 8 phases. Each phase ends with a checkpoint you can verify with a multimeter before moving on. This catches wiring mistakes early when they're easy to fix.

```
Phase 1: Power section (buck converter)
Phase 2: Probe voltage dividers (resistors + caps)
Phase 3: ADS1115 socket
Phase 4: Fan driver (MOSFET circuit)
Phase 5: Buzzer + connectors
Phase 6: Panel-mount components
Phase 7: Wiring harness (ribbon cable + external connections)
Phase 8: Enclosure assembly + final test
```

---

### Phase 1: Power Section

**Goal**: Mount the MP1584EN buck converter module and establish the 12V input and 5V output rails on the perfboard.

> **Before you begin**: Connect 12V to the MP1584EN module **off the perfboard** and adjust the trimpot with a small screwdriver until the output reads **5.0V** on your multimeter. This prevents accidental over-voltage to the ESP32.

#### Steps

1. **Plan your layout.** Place the MP1584EN module in the upper-left area of the 50x70mm perfboard. The module is 22x17mm and has 4 pins (IN+, IN-, OUT+, OUT-). Leave room to the right for the ADS1115 and voltage dividers.

   > Photo placeholder
   > *Photo: Perfboard with component placement marked (use a marker or tape to outline positions)*

2. **Solder the MP1584EN module.** Insert the 4 pins through the perfboard and solder from the back side. The module should sit flush against the board.

   > Photo placeholder
   > *Photo: MP1584EN soldered to perfboard, showing pin positions*

3. **Create power rails.** Using bare wire or solder bridges on the back of the perfboard:
   - Run a **12V trace** (red wire) from the MP1584EN IN+ pad toward the board edge where the barrel jack wires will connect. Also extend it toward the fan driver area (lower-left).
   - Run a **5V trace** (orange wire) from the MP1584EN OUT+ pad toward the right side of the board (where the WT32 and servo connections will go).
   - Run a **GND trace** (black wire) across the bottom of the board, connecting MP1584EN IN- and OUT- together. This is your common ground rail.

   > Photo placeholder
   > *Photo: Back of perfboard showing power rail traces/wires*

4. **Solder barrel jack wires.** Solder two ~10cm wires to the perfboard power input pads:
   - Red wire for 12V (will connect to barrel jack tip/center pin)
   - Black wire for GND (will connect to barrel jack sleeve)
   - Leave the other ends free for now; they'll connect to the panel-mount barrel jack in Phase 6.

#### Checkpoint 1

- [ ] With the barrel jack wires temporarily connected to a 12V supply, measure:
  - 12V between the IN+ pad and GND: **~12V**
  - 5V between the OUT+ pad and GND: **5.0V** (within 4.9-5.1V)
- [ ] Disconnect power before proceeding.

---

### Phase 2: Probe Voltage Dividers

**Goal**: Install the three 10K reference resistors and 0.1uF filter capacitors that form the voltage divider circuits for the temperature probes.

#### How the Probe Circuit Works

Each probe is an NTC (negative temperature coefficient) thermistor. It forms a voltage divider with a fixed 10K resistor:

```
3.3V ──[10K resistor]──┬──[NTC probe]── GND
                        |
                     ADC input
                        |
                     [0.1uF]
                        |
                       GND
```

The ADS1115 reads the voltage at the junction. As the probe heats up, its resistance drops, and the voltage at the junction changes. The firmware converts this voltage to temperature using the Steinhart-Hart equation.

#### Steps

1. **Install R1, R2, R3 (10K 1% resistors).** Place three 10K metal film resistors vertically in a row on the perfboard, to the right of the buck converter. Space them about 10mm apart. One lead of each connects to a 3.3V rail trace; the other lead goes to the junction point.

   > Photo placeholder
   > *Photo: Three 10K resistors installed on perfboard*

2. **Install C1, C2, C3 (0.1uF capacitors).** Place each capacitor near its corresponding resistor. One lead connects to the same junction point as the resistor; the other lead connects to the GND rail.

   > Photo placeholder
   > *Photo: Filter capacitors installed next to resistors*

3. **Create junction traces.** On the back of the perfboard, solder short traces or wire jumpers connecting each resistor-capacitor junction to a pad that will later wire to the ADS1115 analog input (A0, A1, A2).

4. **Run probe jack wires.** From each junction, also run a trace/pad for the wire that will go to the panel-mount 2.5mm probe jack. The other side of the probe jack connects to GND.

   > Photo placeholder
   > *Photo: Back of board showing voltage divider wiring*

5. **Create a 3.3V bus.** Run a trace connecting the top of all three 10K resistors together. This 3.3V bus will later connect to the WT32-SC01 Plus 3.3V output.

   > Photo placeholder
   > *Photo: 3.3V bus trace connecting all three dividers*

#### Checkpoint 2

- [ ] Continuity test: Each resistor's top lead connects to the 3.3V bus (all three should be connected together).
- [ ] Continuity test: Each capacitor's bottom lead connects to the GND rail.
- [ ] Each junction point (resistor bottom + cap top) is **isolated** from the other two junctions (no shorts between A0, A1, A2 points).
- [ ] Resistance from each junction to GND: **approximately 10K ohms** (reading through the resistor to the 3.3V bus, which is floating).

---

### Phase 3: ADS1115 Socket

**Goal**: Install female pin headers as a socket so the ADS1115 breakout can be inserted and removed without desoldering.

#### Steps

1. **Cut female pin headers.** The ADS1115 breakout board typically has 10 pins (some boards vary). Cut your female header strips to match your specific ADS1115 breakout board's pin layout.

   > Photo placeholder
   > *Photo: Female pin headers cut to size next to ADS1115 breakout*

2. **Position the socket.** Place the headers on the perfboard to the right of the voltage dividers. Insert the ADS1115 breakout into the headers to verify alignment, then remove the breakout and solder the headers.

   > Photo placeholder
   > *Photo: Female header socket soldered to perfboard*

3. **Wire the ADS1115 connections.** On the back of the perfboard, solder wires/traces from the socket pins to:

   | ADS1115 Pin | Connects To |
   |-------------|-------------|
   | VDD | 3.3V bus (same as probe resistors) |
   | GND | GND rail |
   | SDA | Pad for I2C SDA wire (to GPIO10) |
   | SCL | Pad for I2C SCL wire (to GPIO11) |
   | A0 | Probe 1 (Pit) junction |
   | A1 | Probe 2 (Meat 1) junction |
   | A2 | Probe 3 (Meat 2) junction |
   | A3 | Leave unconnected (spare) |
   | ADDR | Connect to GND (sets I2C address 0x48) |

   > Photo placeholder
   > *Photo: Back of board showing ADS1115 socket wiring*

4. **Insert the ADS1115 breakout.** Gently press the breakout board into the socket. It should seat firmly but be removable.

   > Photo placeholder
   > *Photo: ADS1115 breakout seated in socket*

#### Checkpoint 3

- [ ] ADS1115 VDD pin has continuity to the 3.3V bus.
- [ ] ADS1115 GND pin has continuity to the GND rail.
- [ ] ADS1115 ADDR pin has continuity to GND.
- [ ] A0, A1, A2 each have continuity to their respective probe junction points (and NOT to each other).
- [ ] SDA and SCL pads are isolated (no continuity between them).

---

### Phase 4: Fan Driver (MOSFET Circuit)

**Goal**: Install the IRLZ44N MOSFET and gate pulldown resistor to switch the 12V blower fan via PWM from GPIO12.

#### How the Fan Driver Works

```
        12V
         |
      Fan (+)
         |
      Fan (-)
         |
       Drain
     ┌───┤
     |   | IRLZ44N
     |  Gate ──── GPIO12 (PWM)
     |   |
    [10K] R4 (gate pulldown)
     |   |
    GND Source
          |
         GND
```

The MOSFET acts as a switch. When GPIO12 goes high (3.3V), the MOSFET turns on and current flows through the fan. The 10K pulldown resistor ensures the gate stays low (fan off) when GPIO12 is not actively driving it (e.g., during boot).

#### Steps

1. **Install Q1 (IRLZ44N MOSFET).** The IRLZ44N is in a TO-220 package with three legs: Gate, Drain, Source (left to right, facing the label). Place it in the lower-left area of the perfboard with the metal tab facing the board edge (for heat dissipation).

   > Photo placeholder
   > *Photo: IRLZ44N positioned on perfboard, pin labels visible*

2. **Solder the MOSFET pins.** Solder all three legs from the back. The pins are:
   - **Gate** (left): Will connect to GPIO12 via signal wire
   - **Drain** (center): Will connect to the fan's negative wire
   - **Source** (right): Connects to GND rail

3. **Install R4 (10K gate pulldown resistor).** Solder a 10K resistor between the Gate pin and GND. This keeps the gate pulled low when GPIO12 is floating (during ESP32 boot).

   > Photo placeholder
   > *Photo: 10K resistor connecting MOSFET gate to GND*

4. **Wire the Source to GND.** Connect the Source pin to the GND rail with a trace or wire on the back of the board.

5. **Wire the Drain.** Connect the Drain pin to a pad where the fan's negative wire will attach. Also run a trace from a nearby pad to the 12V rail for the fan's positive wire.

6. **Create fan connection pads.** Create two pads near the board edge for the fan wires:
   - Fan (+): Connected to 12V rail
   - Fan (-): Connected to MOSFET Drain

   > Photo placeholder
   > *Photo: Fan connection pads on perfboard edge*

7. **Wire the Gate signal.** Run a wire/trace from the Gate to a pad that will connect to GPIO12 through the ribbon cable.

#### Checkpoint 4

- [ ] MOSFET Source to GND: **continuity** (0 ohms).
- [ ] MOSFET Gate to GND: **~10K ohms** (through the pulldown resistor).
- [ ] MOSFET Drain to GND: **no continuity** (MOSFET is off; should read open/very high resistance).
- [ ] Fan (+) pad to 12V rail: **continuity**.
- [ ] Gate pad is isolated from Drain and Source (no accidental shorts).

---

### Phase 5: Buzzer and Remaining Connections

**Goal**: Install the piezo buzzer and create all remaining connection pads for the ribbon cable.

#### Steps

1. **Install BZ1 (piezo buzzer).** Solder the buzzer to the perfboard. Note the polarity:
   - **Positive (+)**: Connects to a pad for GPIO14
   - **Negative (-)**: Connects to GND rail

   > Photo placeholder
   > *Photo: Piezo buzzer soldered to perfboard*

2. **Create servo connection pads.** The servo has three wires:
   - **Orange** (signal): Pad for GPIO13
   - **Red** (VCC): Pad connected to 5V rail
   - **Brown** (GND): Pad connected to GND rail

   > Photo placeholder
   > *Photo: Servo connection pads labeled on perfboard*

3. **Create the ribbon cable header.** Create a row of pads (or solder a pin header) for the 8-pin ribbon cable connection. The pin mapping is:

   | Ribbon Pin | Signal | Perfboard Connection |
   |------------|--------|---------------------|
   | 1 | GPIO10 (SDA) | ADS1115 SDA pad |
   | 2 | GPIO11 (SCL) | ADS1115 SCL pad |
   | 3 | GPIO12 (Fan PWM) | MOSFET Gate pad |
   | 4 | GPIO13 (Servo PWM) | Servo signal pad |
   | 5 | GPIO14 (Buzzer) | Buzzer (+) pad |
   | 6 | 3.3V | 3.3V bus (probe dividers) |
   | 7 | 5V | 5V rail (from buck converter) |
   | 8 | GND | GND rail |

   > Photo placeholder
   > *Photo: Ribbon cable header/pads on perfboard edge*

4. **Final perfboard wiring.** Verify all traces on the back of the board connect correctly. Use your multimeter to check every connection in the table above.

   > Photo placeholder
   > *Photo: Complete back of perfboard showing all traces and wiring*

   > Photo placeholder
   > *Photo: Complete front of perfboard with all components installed*

#### Checkpoint 5

- [ ] Buzzer (+) to GPIO14 pad: **continuity**.
- [ ] Buzzer (-) to GND rail: **continuity**.
- [ ] Servo signal pad to GPIO13 pad: **continuity**.
- [ ] Servo VCC pad to 5V rail: **continuity**.
- [ ] Every ribbon cable pad connects to its intended destination and nothing else.
- [ ] **Full board continuity audit** - check for shorts between:
  - 12V and GND: **no continuity**
  - 5V and GND: **no continuity**
  - 3.3V and GND: **no continuity**
  - 12V and 5V: **no continuity**
  - All signal lines isolated from each other

---

### Phase 6: Panel-Mount Components

**Goal**: Install the probe jacks and barrel jack into the 3D-printed enclosure rear shell, and wire them to the carrier board.

#### Steps

1. **Thread the 2.5mm probe jacks.** Insert the three 2.5mm mono panel-mount jacks through the probe holes in the rear shell bottom edge. Secure each with its mounting nut from inside.

   > Photo placeholder
   > *Photo: Three probe jacks installed in rear shell, viewed from outside*

2. **Thread the DC barrel jack.** Insert the panel-mount barrel jack through its hole on the rear shell. Secure with its mounting nut.

   > Photo placeholder
   > *Photo: Barrel jack installed in rear shell*

3. **Wire the probe jacks.** For each 2.5mm mono jack, solder two wires (~8cm each):
   - **Tip lug**: Connect to the corresponding probe junction pad on the carrier board (Probe 1 = A0 junction, Probe 2 = A1 junction, Probe 3 = A2 junction)
   - **Sleeve lug**: Connect to the GND rail on the carrier board

   > Photo placeholder
   > *Photo: Close-up of solder connections on a probe jack lug*

4. **Wire the barrel jack.** Solder the pre-cut wires from Phase 1 to the barrel jack:
   - **Center/tip pin**: Red wire (12V from carrier board)
   - **Sleeve pin**: Black wire (GND from carrier board)

   > Photo placeholder
   > *Photo: Barrel jack wired to carrier board power input*

#### Checkpoint 6

- [ ] With a probe plugged into each jack, check continuity from the jack's tip lug to the corresponding junction pad on the carrier board.
- [ ] Each jack's sleeve lug has continuity to the carrier board GND rail.
- [ ] Barrel jack center pin has continuity to the carrier board 12V input.
- [ ] Barrel jack sleeve has continuity to the carrier board GND rail.

---

### Phase 7: Wiring Harness

**Goal**: Connect the carrier board to the WT32-SC01 Plus via the ribbon cable, and attach the fan and servo leads.

#### Steps

1. **Connect the ribbon cable.** Plug the 8-pin ribbon cable (included with the WT32-SC01 Plus) between:
   - The WT32-SC01 Plus extension connector
   - The ribbon cable header/pads on the carrier board

   > **Important**: Verify pin 1 orientation. The WT32-SC01 Plus extension connector has a pin 1 indicator. Match it to pin 1 on your carrier board header (GPIO10/SDA).

   > Photo placeholder
   > *Photo: Ribbon cable connecting carrier board to WT32-SC01 Plus*

2. **Connect the fan.** Solder or connect the 5015 blower fan's wires to the fan pads on the carrier board:
   - Red wire to Fan (+) pad (12V)
   - Black wire to Fan (-) pad (MOSFET drain)

   Route the fan wire through the right-side cable slot in the rear shell.

   > Photo placeholder
   > *Photo: Fan wires connected to carrier board*

3. **Connect the servo.** Plug the servo connector into the servo pads (or solder if using direct wiring):
   - Orange wire to servo signal pad (GPIO13)
   - Red wire to servo VCC pad (5V)
   - Brown wire to servo GND pad

   Route the servo wire through the right-side cable slot in the rear shell.

   > Photo placeholder
   > *Photo: Servo connector wired to carrier board*

#### Checkpoint 7 - Power-On Test

This is the first time you'll power everything up together. **Double-check all connections before applying power.**

1. **Pre-power checklist:**
   - [ ] 12V and GND are not shorted (check barrel jack with multimeter)
   - [ ] 5V and GND are not shorted
   - [ ] No loose wires or solder blobs that could cause shorts
   - [ ] Ribbon cable is properly oriented (pin 1 matches)

2. **Apply power.** Connect the 12V power supply to the barrel jack.

3. **Verify voltages:**
   - [ ] 5V rail: **5.0V** (measure at WT32 5V pin or servo VCC pad)
   - [ ] 3.3V rail: **3.3V** (measure at 3.3V bus or ADS1115 VDD)
   - [ ] WT32-SC01 Plus display turns on and shows the boot screen or setup wizard

4. **Verify I2C (probe readings):**
   - [ ] If firmware is flashed, the touchscreen should show temperature readings. Plug in a probe and verify you see a temperature value (room temp, roughly 70-75F / 21-24C).
   - [ ] If no firmware yet, this will be verified after flashing.

5. **Verify fan:**
   - [ ] If firmware is flashed and setup wizard runs, the hardware test step should spin the fan briefly.
   - [ ] Manual test: Briefly touch a jumper wire from the MOSFET gate to 3.3V. The fan should spin. **Remove the jumper quickly** (this is full speed with no PWM control).

6. **Verify servo:**
   - [ ] The setup wizard hardware test should sweep the servo.

7. **Verify buzzer:**
   - [ ] The setup wizard hardware test should beep the buzzer.

---

### Phase 8: Enclosure Assembly

**Goal**: Mount everything in the 3D-printed enclosure and close it up.

#### Steps

1. **Install heat-set inserts (optional).** If using threaded inserts, press M3 heat-set inserts into the 4 screw bosses on the rear shell using a soldering iron set to 230C. Let cool completely before proceeding.

   > Photo placeholder
   > *Photo: Heat-set inserts being pressed into rear shell screw bosses*

2. **Mount the WT32-SC01 Plus in the front bezel.** Place the display face-down into the bezel. The glass sits against the bezel lip. Secure with 4x M3x6mm screws through the PCB mounting holes.

   > Photo placeholder
   > *Photo: WT32-SC01 Plus mounted in front bezel, viewed from back*

3. **Mount the carrier board in the rear shell.** Place the carrier board onto the standoffs in the rear shell. Optionally secure with M3x6mm screws.

   > Photo placeholder
   > *Photo: Carrier board seated on rear shell standoffs*

4. **Route all wires.** Ensure wires are neatly routed and won't get pinched when closing the enclosure:
   - Ribbon cable from carrier board to WT32 extension connector
   - Fan and servo wires through the right-side cable slots
   - Probe jack and barrel jack wires between shell panel and carrier board

   > Photo placeholder
   > *Photo: All wires neatly routed inside the enclosure*

5. **Close the enclosure.** Mate the front bezel to the rear shell. Align the screw bosses and secure with 4x M3x8mm screws.

   > Photo placeholder
   > *Photo: Fully assembled and closed enclosure*

6. **Attach the kickstand (optional).** Press the kickstand hinge tab into the slot on the rear of the shell. It should click in and swing freely.

   > Photo placeholder
   > *Photo: Kickstand attached and deployed*

---

## First Boot & Firmware

### Flashing Firmware (First Time - USB Required)

1. Connect the WT32-SC01 Plus to your computer via USB-C.
2. Build and flash the firmware:
   ```bash
   pio run -e wt32_sc01_plus --target upload
   ```
3. Upload the web UI files to LittleFS:
   ```bash
   pio run -e wt32_sc01_plus --target uploadfs
   ```
4. The setup wizard should appear on the touchscreen.

### Setup Wizard

The touchscreen will walk you through:
1. **Welcome** - Project name and version
2. **Units** - Choose Fahrenheit or Celsius
3. **Wi-Fi** - Scan the QR code with your phone to connect to the `BBQ-Setup` AP, then enter your Wi-Fi credentials in the captive portal
4. **Probe check** - Plug in probes and verify live readings
5. **Hardware test** - Fan spins, servo sweeps, buzzer beeps
6. **Done** - Dashboard appears

### Future Firmware Updates (OTA)

After initial USB flash, update wirelessly:
1. Navigate to `http://bbq.local/update` in your browser
2. Upload the new `.bin` file
3. Device reboots with updated firmware (config and session data preserved)

---

## Troubleshooting

### No Display / Nothing Happens on Power-On

- Check 5V rail with multimeter (should be 5.0V)
- Check that the MP1584EN trimpot is set correctly
- Verify ribbon cable orientation (pin 1 alignment)
- Try powering the WT32 directly via its USB-C port to isolate power issues

### Probe Reads "---" (Disconnected)

- Check continuity from the probe jack tip lug to the ADS1115 analog input
- Check that the 10K resistor in that probe's voltage divider is connected to 3.3V
- Try a different probe in the same jack
- Try the same probe in a different jack to isolate jack vs. probe vs. ADC channel

### Probe Reads "ERR" (Shorted)

- The probe wires may be shorted. Check the 2.5mm jack for solder bridges
- Check for shorts between the junction point and GND

### Probe Temperature is Wrong

- Verify the 10K reference resistor is actually 10K (1% tolerance = 9.9K to 10.1K)
- Check that the correct Steinhart-Hart coefficients are configured for your probe type
- Use the calibration offset in settings (ice water = 32F/0C, boiling water = 212F/100C adjusted for altitude)

### Fan Doesn't Spin

- Check 12V at the fan (+) pad
- Check that the MOSFET gate is receiving the PWM signal (put multimeter on AC voltage mode on the gate pin while the firmware is commanding fan output)
- Manually test: briefly touch gate to 3.3V. If the fan spins, the MOSFET circuit is fine and the issue is the signal from GPIO12
- Check the 10K gate pulldown - if it's shorted or too low value, the gate may not reach threshold

### Servo Doesn't Move

- Check 5V at the servo VCC pad
- Check that GPIO13 is connected to the servo signal wire (orange)
- Try the servo with a known-good signal source (e.g., Arduino servo sweep example)

### Buzzer Doesn't Sound

- Check polarity (+ to GPIO14, - to GND)
- Check that GPIO14 is connected through the ribbon cable
- Some passive buzzers need a specific frequency drive. Active buzzers just need DC.

### Wi-Fi Won't Connect

- During setup: the `BBQ-Setup` AP should appear. If not, factory reset (hold touchscreen 10 seconds during boot splash).
- After setup: verify SSID and password in config. Factory reset and re-run wizard if needed.
- Check that your router is 2.4 GHz (ESP32 does not support 5 GHz).

### I2C Errors / ADS1115 Not Found

- Check SDA and SCL wiring (GPIO10 = SDA, GPIO11 = SCL; don't swap them)
- Check that ADS1115 ADDR pin is connected to GND (address 0x48)
- Check that the ADS1115 breakout is fully seated in its socket
- Run an I2C scanner sketch to verify the device is detected

---

## Pin Reference

Quick reference for all connections between the carrier board and WT32-SC01 Plus:

| WT32 GPIO | Function | Carrier Board Destination |
|---|---|---|
| GPIO10 | I2C SDA | ADS1115 SDA pin |
| GPIO11 | I2C SCL | ADS1115 SCL pin |
| GPIO12 | Fan PWM | IRLZ44N Gate (via R4 pulldown) |
| GPIO13 | Servo PWM | MG90S servo signal (orange wire) |
| GPIO14 | Buzzer | Piezo buzzer (+) |
| 3.3V | Power | ADS1115 VDD, probe voltage dividers |
| 5V | Power (input) | MP1584EN OUT+, servo VCC |
| GND | Ground | Common ground rail (everything) |

---

## Photo Checklist

As you build, take photos at these key moments. They'll be useful for others following this guide and for troubleshooting if something isn't working. Replace the placeholder images above with your actual build photos.

- [ ] `perfboard-layout-planning.jpg` - Perfboard dry-fit with all components placed
- [ ] `perfboard-back-traces.jpg` - Complete back of perfboard showing solder traces
- [ ] `phase1-layout-planning.jpg` - Component placement marked on perfboard
- [ ] `phase1-buck-converter-soldered.jpg` - MP1584EN installed
- [ ] `phase1-power-rails.jpg` - Power rail traces on back of board
- [ ] `phase2-resistors-placed.jpg` - Three 10K resistors installed
- [ ] `phase2-caps-placed.jpg` - 0.1uF capacitors installed
- [ ] `phase2-divider-wiring.jpg` - Voltage divider wiring on back
- [ ] `phase2-3v3-bus.jpg` - 3.3V bus connecting dividers
- [ ] `phase3-headers-cut.jpg` - Female headers for ADS1115 socket
- [ ] `phase3-socket-soldered.jpg` - Socket installed on perfboard
- [ ] `phase3-ads1115-wiring.jpg` - ADS1115 socket wiring on back
- [ ] `phase3-ads1115-installed.jpg` - ADS1115 breakout seated in socket
- [ ] `phase4-mosfet-placed.jpg` - IRLZ44N on perfboard
- [ ] `phase4-gate-pulldown.jpg` - 10K gate pulldown resistor
- [ ] `phase4-fan-pads.jpg` - Fan connection pads
- [ ] `phase5-buzzer-installed.jpg` - Piezo buzzer soldered
- [ ] `phase5-servo-pads.jpg` - Servo connection pads
- [ ] `phase5-ribbon-header.jpg` - Ribbon cable header on perfboard
- [ ] `phase5-board-back-complete.jpg` - Complete back of perfboard
- [ ] `phase5-board-front-complete.jpg` - Complete front of perfboard
- [ ] `phase6-probe-jacks-mounted.jpg` - Probe jacks in rear shell
- [ ] `phase6-barrel-jack-mounted.jpg` - Barrel jack in rear shell
- [ ] `phase6-probe-jack-wiring.jpg` - Probe jack solder connections
- [ ] `phase6-barrel-jack-wiring.jpg` - Barrel jack wiring
- [ ] `phase7-ribbon-cable-connected.jpg` - Ribbon cable connection
- [ ] `phase7-fan-connected.jpg` - Fan wires on carrier board
- [ ] `phase7-servo-connected.jpg` - Servo wiring
- [ ] `phase8-heat-set-inserts.jpg` - Heat-set insert installation
- [ ] `phase8-display-mounted.jpg` - Display in front bezel
- [ ] `phase8-carrier-mounted.jpg` - Carrier board in rear shell
- [ ] `phase8-wire-routing.jpg` - Wire routing inside enclosure
- [ ] `phase8-enclosure-closed.jpg` - Fully assembled enclosure
- [ ] `phase8-kickstand.jpg` - Kickstand attached

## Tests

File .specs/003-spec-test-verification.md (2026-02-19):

# 003: Spec Test Plan Verification & PR Alignment

**Branch**: `feature/spec-test-verification`
**Created**: 2026-02-18

## Summary

Update the `/feature` and `/ship` lifecycle commands so that test plan items in the spec are checked off during implementation, and the PR body pulls its test plan directly from the spec rather than generating a new one. This ensures the spec remains the single source of truth throughout the lifecycle.

## Requirements

- During `/feature` Step 8 (Implement), after verifying each test plan item, update the spec file to check off the item (`- [ ]` → `- [x]`)
- During `/ship` Step 4 (Create PR), read the spec's test plan and summary and use them directly in the PR body instead of writing new ones
- The PR summary should come from the spec's Summary section
- The PR test plan should be the spec's Test Plan section (already checked off from implementation)
- If a test plan item genuinely wasn't verified, it should remain unchecked

## Design

### `feature.md` Changes (Step 8)

Add explicit instructions to update the spec file's test plan checkboxes as each item is verified. After running builds/tests and confirming requirements, edit the spec file (in the worktree) to mark each passing item as `[x]`. This makes the spec a living document that reflects verification status.

### `ship.md` Changes (Step 4)

Replace the hardcoded PR body template with instructions to:
1. Read the spec file matching the branch name
2. Extract the Summary section for the PR summary
3. Extract the Test Plan section (with its checked/unchecked checkboxes) for the PR test plan
4. Use these directly in the PR body

## Files to Modify

| File | Change |
|---|---|
| `.claude/commands/feature.md` | Update Step 8 to check off test plan items in the spec file after verification |
| `.claude/commands/ship.md` | Update Step 4 to pull summary and test plan from the spec file |

## Test Plan

- [x] `feature.md` Step 8 includes instructions to check off test plan items in the spec
- [x] `ship.md` Step 4 includes instructions to read the spec's Summary and Test Plan
- [x] `ship.md` Step 4 PR body template uses spec content instead of hardcoded example
- [x] Both files have valid markdown and no syntax errors

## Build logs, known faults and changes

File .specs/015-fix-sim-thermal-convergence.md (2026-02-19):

# 015: Fix Simulator Thermal Model Pit Temperature Convergence

**Branch**: `feature/fix-sim-thermal-convergence`
**Created**: 2026-02-18

## Summary

The simulator's pit temperature never reaches the setpoint (225°F) — it hovers around 216-217°F. The root cause is that `maxAchievable` in `updatePitTemp()` depends on instantaneous airflow, which drops when the PID backs off near setpoint, creating a self-defeating feedback loop. The fix decouples `maxAchievable` from instantaneous airflow by making `fireEnergy` a stateful variable that responds to airflow over time, giving the charcoal fire realistic thermal mass.

## Requirements

- Pit temperature must converge to the setpoint (e.g., 225°F) during a normal cook simulation
- Fire energy should be replenished by airflow (oxygen feeds coals) and consumed by natural decay
- With damper closed, fire should barely sustain (minimal air leakage) — not die instantly, not grow
- Fire-out profile must still work (rapid fire energy decay when `fireOut` flag is set)
- All existing cook profiles (normal, stall, hot-fast, temp-change, lid-open, fire-out, probe-disconnect) must produce realistic behavior
- No changes to the firmware PID, split-range, or any non-simulator code

## Design

### Current Bug (detailed trace)

In `fan_and_damper` mode, when PID output settles around 76% (integral maxed at 2000):
- `damperPct = 76%`, `fanPct ≈ 65.7%`
- `airflow = 0.76 * max(0.15, 0.657) = 0.76 * 0.657 ≈ 0.499`
- `maxAchievable = 70 + 330 * 0.89 * 0.499 ≈ 216.5°F`

The pit asymptotically approaches 216.5°F but can never exceed it.

### Fix: Airflow-Driven Fire Energy Model

**Key insight**: In a real charcoal smoker, the fire has thermal mass. Closing the damper doesn't instantly cool the fire — it slowly starves it of oxygen. The model should reflect this by making `fireEnergy` respond to airflow over time, not having airflow directly cap temperature.

**Changes to `update()` method** — Replace the fire energy decay block with an airflow-aware model:

```cpp
// Compute effective airflow for fire energy model
{
    float naturalDraft = 0.15f;
    float damperOpen = damperPercent / 100.0f;
    float fanFlow = fanPercent / 100.0f;
    float effectiveAirflow = damperOpen * fmaxf(naturalDraft, fanFlow);

    if (fireOut) {
        fireEnergy = fmaxf(0, fireEnergy - 0.0005f * dt);
    } else {
        // Minimal air leakage keeps coals barely smoldering even with damper closed
        float airflow = fmaxf(effectiveAirflow, 0.03f);
        float replenishRate = 0.0001f;
        float netChange = (airflow * replenishRate - fireDecayRate_) * dt;
        fireEnergy = fmaxf(0.05f, fminf(1.0f, fireEnergy + netChange));
    }
}
```

**Changes to `updatePitTemp()` method** — Remove airflow calculation, use fireEnergy directly:

```cpp
float maxFireTemp = 400.0f;
float maxAchievable = ambientTemp + (maxFireTemp - ambientTemp) * fireEnergy;
```

### Tuning Verification

- `fireDecayRate_ = 0.000003f`, `replenishRate = 0.0001f`
- Equilibrium airflow: `0.000003 / 0.0001 = 0.03` (matches minLeakage)
- At damper closed (PID=0): airflow clamped to 0.03 → exact equilibrium, fire barely sustains
- At PID ~30%: airflow ≈ 0.045 → slow fire energy gain
- At PID 100%: airflow = 1.0 → fire energy maxes quickly
- With fireEnergy = 1.0: `maxAchievable = 70 + 330 = 400°F` (well above 225)
- Fire can sustain setpoint as long as `fireEnergy > 0.47`

### Profile Impact

| Profile | Expected behavior |
|---|---|
| normal | Pit converges to 225°F (FIXED) |
| stall | Pit converges to 225°F, meat stalls as before |
| hot-fast | Pit converges to 300°F (maxAchievable = 400 > 300) |
| temp-change | Pit reaches 225, then 275 after setpoint change |
| lid-open | Pit drops on lid open, recovers after close; fire energy stable |
| fire-out | Fire energy decays rapidly via existing `fireOut` path |
| probe-disconnect | Pit behavior unchanged, probe disconnect still works |

## Files to Modify

| File | Change |
|---|---|
| `firmware/src/simulator/sim_thermal.cpp` | Replace fire energy decay in `update()` with airflow-driven model; simplify `maxAchievable` in `updatePitTemp()` to use `fireEnergy` only |

## Test Plan

- [x] Simulator builds: `pio run -e simulator`
- [ ] Run simulator with normal profile: pit temp converges to 225°F (not stuck at 216-217)
- [ ] Run simulator with hot-fast profile: pit temp converges to 300°F
- [x] Firmware builds: `pio run -e wt32_sc01_plus`
- [x] Desktop tests pass: `pio test -e native` (130/130 passed)

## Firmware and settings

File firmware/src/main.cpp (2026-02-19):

#ifndef NATIVE_BUILD

#include <Arduino.h>
#include "config.h"
#include "split_range.h"

// --- Module headers ---
#include "temp_manager.h"
#include "pid_controller.h"
#include "fan_controller.h"
#include "servo_controller.h"
#include "config_manager.h"
#include "cook_session.h"
#include "alarm_manager.h"
#include "error_manager.h"
#include "wifi_manager.h"
#include "web_server.h"
#include "ota_manager.h"
#include "display/ui_init.h"
#include "display/ui_update.h"
#include "display/ui_setup_wizard.h"
#include "display/ui_boot_splash.h"

// --- Module instances ---
TempManager     tempManager;
PidController   pidController;
FanController   fanController;
ServoController servoController;
ConfigManager   configManager;
CookSession     cookSession;
AlarmManager    alarmManager;
ErrorManager    errorManager;
WifiManager     wifiManager;
BBQWebServer    webServer;
OtaManager      otaManager;

// --- Control state ---
static float    g_setpoint       = 225.0f;   // Default pit setpoint (degrees F)
static float    g_prevSetpoint   = 225.0f;   // Previous setpoint for change detection
static bool     g_pitReached     = false;     // Has pit ever reached setpoint?
static uint32_t g_cookStartTime  = 0;         // Epoch when cook timer started
static unsigned long g_lastPidMs = 0;         // Last PID computation timestamp

// --- Boot phase state machine ---
enum class BootPhase { SPLASH, WIZARD, RUNNING };
static BootPhase    g_bootPhase    = BootPhase::SPLASH;
static unsigned long g_wizardDoneMs = 0;

// --- CookSession data-source callbacks ---
// These free functions bridge the global module instances into the function-pointer
// interface that CookSession::setDataSources() expects.

static float cb_getPitTemp()   { return tempManager.getPitTemp(); }
static float cb_getMeat1Temp() { return tempManager.getMeat1Temp(); }
static float cb_getMeat2Temp() { return tempManager.getMeat2Temp(); }

static uint8_t cb_getFanPct() {
    return static_cast<uint8_t>(fanController.getCurrentSpeedPct());
}

static uint8_t cb_getDamperPct() {
    return static_cast<uint8_t>(servoController.getCurrentPositionPct());
}

static uint8_t cb_getFlags() {
    uint8_t flags = 0;
    if (pidController.isLidOpen())                    flags |= DP_FLAG_LID_OPEN;
    if (!tempManager.isConnected(PROBE_PIT))          flags |= DP_FLAG_PIT_DISC;
    if (!tempManager.isConnected(PROBE_MEAT1))        flags |= DP_FLAG_MEAT1_DISC;
    if (!tempManager.isConnected(PROBE_MEAT2))        flags |= DP_FLAG_MEAT2_DISC;
    if (errorManager.isFireOut())                     flags |= DP_FLAG_ERROR_FIREOUT;

    AlarmType activeAlarms[MAX_ACTIVE_ALARMS];
    uint8_t count = alarmManager.getActiveAlarms(activeAlarms, MAX_ACTIVE_ALARMS);
    for (uint8_t i = 0; i < count; i++) {
        if (activeAlarms[i] == AlarmType::PIT_HIGH ||
            activeAlarms[i] == AlarmType::PIT_LOW)    flags |= DP_FLAG_ALARM_PIT;
        if (activeAlarms[i] == AlarmType::MEAT1_DONE) flags |= DP_FLAG_ALARM_MEAT1;
        if (activeAlarms[i] == AlarmType::MEAT2_DONE) flags |= DP_FLAG_ALARM_MEAT2;
    }
    return flags;
}

// --- WebSocket command callbacks ---
static void ws_onSetpoint(float sp) {
    g_setpoint = sp;
}

static void ws_onAlarm(const char* probe, float target) {
    if (strcmp(probe, "meat1") == 0)      alarmManager.setMeat1Target(target);
    else if (strcmp(probe, "meat2") == 0) alarmManager.setMeat2Target(target);
    else if (strcmp(probe, "pitBand") == 0) alarmManager.setPitBand(target);
}

static void ws_onFanMode(const char* mode) {
    configManager.setFanMode(mode);
    ui_update_settings_state(configManager.isFahrenheit(), configManager.getFanMode());
}

static void ws_onSession(const char* action, const char* format) {
    if (strcmp(action, "new") == 0) {
        cookSession.endSession();
        cookSession.startSession();
        g_cookStartTime = 0;
        g_pitReached = false;
        ui_graph_clear();
    }
}

// --- Display timing ---
static unsigned long g_lastDisplayMs = 0;
static unsigned long g_lastGraphMs   = 0;

// --- UI callbacks ---
static void ui_cb_setpoint(float sp) {
    g_setpoint = sp;
}

static void ui_cb_meat_target(uint8_t probe, float target) {
    if (probe == 1) alarmManager.setMeat1Target(target);
    if (probe == 2) alarmManager.setMeat2Target(target);
}

static void ui_cb_alarm_ack() {
    alarmManager.acknowledge();
}

static void ui_cb_units(bool isFahrenheit) {
    configManager.setUnits(isFahrenheit ? "F" : "C");
    tempManager.setUseFahrenheit(isFahrenheit);
}

static void ui_cb_fan_mode(const char* mode) {
    configManager.setFanMode(mode);
}

static void ui_cb_new_session() {
    cookSession.endSession();
    cookSession.startSession();
    g_cookStartTime = 0;
    g_pitReached = false;
    ui_graph_clear();
}

static void ui_cb_factory_reset() {
    configManager.factoryReset();
    ESP.restart();
}

// --- Setup wizard hardware test (non-blocking) ---
enum class HwTest { NONE, FAN, SERVO, BUZZER };
static HwTest g_hwTest = HwTest::NONE;
static unsigned long g_hwTestStartMs = 0;

static void wiz_fan_test() {
    fanController.setSpeed(75);
    fanController.update();
    g_hwTest = HwTest::FAN;
    g_hwTestStartMs = millis();
}

static void wiz_servo_test() {
    servoController.setPosition(100);
    g_hwTest = HwTest::SERVO;
    g_hwTestStartMs = millis();
}

static void wiz_buzzer_test() {
    alarmManager.setBuzzer(true);
    g_hwTest = HwTest::BUZZER;
    g_hwTestStartMs = millis();
}

static void wiz_complete() {
    configManager.setSetupComplete(true);
    configManager.save();
    Serial.println("[BOOT] Setup wizard complete");
}

static void ui_cb_wifi_action(const char* action) {
    if (strcmp(action, "disconnect") == 0) {
        wifiManager.disconnect();
    } else if (strcmp(action, "reconnect") == 0) {
        wifiManager.reconnect();
    } else if (strcmp(action, "setup_ap") == 0) {
        wifiManager.startAP();
    }
}

// ---------------------------------------------------------------------------
// setup()
// ---------------------------------------------------------------------------
void setup() {
    // 1. Serial
    Serial.begin(115200);
    delay(500);  // Allow USB-CDC to connect

    Serial.println();
    Serial.println("========================================");
    Serial.printf("  Pit Claw v%s\n", FIRMWARE_VERSION);
    Serial.println("  Board: WT32-SC01 Plus (ESP32-S3)");
    Serial.println("========================================");
    Serial.println();

    // 2. Load configuration from LittleFS
    configManager.begin();
    const AppConfig& cfg = configManager.getConfig();

    // 3. Initialize display and show boot splash immediately
    //    Splash is visible while remaining hardware modules initialize.
    ui_init();
    ui_boot_splash_init();
    ui_tick(10);
    ui_handler();

    // 4. Initialize I2C bus and temperature probes (ADS1115)
    tempManager.begin();

    // Apply per-probe calibration coefficients and offsets from saved config
    for (uint8_t i = 0; i < NUM_PROBES; i++) {
        const ProbeSettings& ps = configManager.getProbeSettings(i);
        tempManager.setCoefficients(i, ps.a, ps.b, ps.c);
        tempManager.setOffset(i, ps.offset);
    }
    tempManager.setUseFahrenheit(configManager.isFahrenheit());

    // 5. Initialize PID controller with saved tunings
    pidController.begin(cfg.pid.kp, cfg.pid.ki, cfg.pid.kd);

    // 6. Initialize fan PWM output
    fanController.begin();

    // 7. Initialize servo / damper output
    servoController.begin();

    // 8. Initialize alarm manager (buzzer)
    alarmManager.begin();
    alarmManager.setPitBand(cfg.alarms.pitBand);

    // 9. Initialize error detection
    errorManager.begin();

    // 10. Connect WiFi (splash screen visible during connection)
    wifiManager.begin();

    // 11. Start HTTP server and WebSocket, pass module references
    webServer.begin();
    webServer.setModules(&tempManager, &pidController, &fanController,
                         &servoController, &configManager, &cookSession,
                         &alarmManager, &errorManager);
    webServer.onSetpoint(ws_onSetpoint);
    webServer.onAlarm(ws_onAlarm);
    webServer.onSession(ws_onSession);
    webServer.onFanMode(ws_onFanMode);

    // 12. Initialize OTA updates (needs the AsyncWebServer to register /update route)
    otaManager.begin(webServer.getAsyncServer());

    // 13. Recover any existing cook session from flash
    cookSession.begin();
    cookSession.setDataSources(cb_getPitTemp, cb_getMeat1Temp, cb_getMeat2Temp,
                               cb_getFanPct, cb_getDamperPct, cb_getFlags);

    // 14. Wire up dashboard callbacks and set initial state
    ui_set_callbacks(ui_cb_setpoint, ui_cb_meat_target, ui_cb_alarm_ack);
    ui_set_settings_callbacks(ui_cb_units, ui_cb_fan_mode, ui_cb_new_session, ui_cb_factory_reset);
    ui_set_wifi_callback(ui_cb_wifi_action);

    // Set initial display state
    ui_update_setpoint(g_setpoint);
    ui_update_meat1_target(alarmManager.getMeat1Target());
    ui_update_meat2_target(alarmManager.getMeat2Target());
    ui_update_settings_state(configManager.isFahrenheit(), configManager.getFanMode());

    // Pre-populate graph from recovered session data
    {
        uint32_t sessionPoints = cookSession.getTotalPointCount();
        for (uint32_t i = 0; i < sessionPoints; i++) {
            const DataPoint* dp = cookSession.getPoint(i);
            if (dp) {
                ui_graph_add_point(
                    dp->pitTemp / 10.0f,
                    dp->meat1Temp / 10.0f,
                    dp->meat2Temp / 10.0f,
                    g_setpoint,
                    (dp->flags & DP_FLAG_PIT_DISC) != 0,
                    (dp->flags & DP_FLAG_MEAT1_DISC) != 0,
                    (dp->flags & DP_FLAG_MEAT2_DISC) != 0
                );
            }
        }
    }

    // 15. Log "Setup complete" with IP address
    Serial.println();
    Serial.printf("[BOOT] Setup complete. IP: %s\n", wifiManager.getIPAddress());
    Serial.println();

    g_lastPidMs = millis();
    g_lastDisplayMs = millis();
    g_lastGraphMs = millis();
}

// ---------------------------------------------------------------------------
// loop()  — target ~100 Hz (10 ms delay at end); modules gate their own timing
// ---------------------------------------------------------------------------
void loop() {
    unsigned long now = millis();

    // --- Boot splash phase: only process LVGL and splash logic ---
    if (g_bootPhase == BootPhase::SPLASH) {
        ui_boot_splash_update();
        if (!ui_boot_splash_is_active()) {
            if (ui_boot_splash_factory_reset_triggered()) {
                Serial.println("[BOOT] Factory reset triggered from splash");
                configManager.factoryReset();
                ESP.restart();
            }
            if (!configManager.isSetupComplete()) {
                Serial.println("[BOOT] First boot — starting setup wizard");
                ui_boot_splash_cleanup();
                ui_wizard_init();
                ui_wizard_set_callbacks(wiz_fan_test, wiz_servo_test,
                                        wiz_buzzer_test, ui_cb_units, wiz_complete);
                g_bootPhase = BootPhase::WIZARD;
            } else {
                ui_boot_splash_cleanup();
                ui_switch_screen(Screen::DASHBOARD);
                g_bootPhase = BootPhase::RUNNING;
                Serial.println("[BOOT] Entering normal operation");
            }
        }
        ui_tick(10);
        ui_handler();
        delay(10);
        return;
    }

    // --- Setup wizard phase: process LVGL, temp readings, and WiFi ---
    if (g_bootPhase == BootPhase::WIZARD) {
        tempManager.update();
        wifiManager.update();

        // Handle hardware test timeouts (non-blocking)
        if (g_hwTest != HwTest::NONE) {
            unsigned long elapsed = now - g_hwTestStartMs;
            switch (g_hwTest) {
                case HwTest::FAN:
                    fanController.update();
                    if (elapsed >= 1000) {
                        fanController.setSpeed(0);
                        fanController.update();
                        g_hwTest = HwTest::NONE;
                    }
                    break;
                case HwTest::SERVO:
                    if (elapsed >= 500) {
                        servoController.setPosition(0);
                        g_hwTest = HwTest::NONE;
                    }
                    break;
                case HwTest::BUZZER:
                    if (elapsed >= 300) {
                        alarmManager.setBuzzer(false);
                        g_hwTest = HwTest::NONE;
                    }
                    break;
                default: break;
            }
        }

        if (ui_wizard_is_active()) {
            if (now - g_lastDisplayMs >= 1000) {
                g_lastDisplayMs = now;
                ui_wizard_update_probes(
                    tempManager.getPitTemp(),
                    tempManager.getMeat1Temp(),
                    tempManager.getMeat2Temp(),
                    tempManager.isConnected(PROBE_PIT),
                    tempManager.isConnected(PROBE_MEAT1),
                    tempManager.isConnected(PROBE_MEAT2));
            }
        } else {
            // Wizard finished — show Done screen for 2 seconds then go to dashboard
            if (g_wizardDoneMs == 0) {
                g_wizardDoneMs = now;
            } else if (now - g_wizardDoneMs >= 2000) {
                ui_switch_screen(Screen::DASHBOARD);
                g_bootPhase = BootPhase::RUNNING;
                Serial.println("[BOOT] Entering normal operation");
            }
        }
        ui_tick(10);
        ui_handler();
        delay(10);
        return;
    }

    // --- Normal running phase ---
    // 1. Read temperatures from all probes (internally gated at TEMP_SAMPLE_INTERVAL_MS)
    tempManager.update();

    // 2. PID computation (every PID_SAMPLE_MS)
    if (now - g_lastPidMs >= PID_SAMPLE_MS) {
        g_lastPidMs = now;

        // Reset integrator on setpoint change for bumpless transfer
        if (g_setpoint != g_prevSetpoint) {
            pidController.resetIntegrator();
            g_pitReached = false;  // Suppress pit-band alarms during ramp to new setpoint
            g_prevSetpoint = g_setpoint;
        }

        // Only compute PID when pit probe is connected. When disconnected,
        // _pidOutput retains its last value to maintain current fire management.
        if (tempManager.isConnected(PROBE_PIT)) {
            float pitTemp = tempManager.getPitTemp();
            pidController.compute(pitTemp, g_setpoint);

            // Track whether pit has ever reached setpoint (within 5 degrees F).
            if (!g_pitReached) {
                if (fabsf(pitTemp - g_setpoint) <= 5.0f) {
                    g_pitReached = true;
                }
            }
        }
    }

    // 3. Mode-aware fan + damper from PID output (split-range coordination)
    {
        SplitRangeOutput sr = splitRange(pidController.getOutput(),
                                         configManager.getFanMode(),
                                         configManager.getFanOnThreshold());
        servoController.setPosition(sr.damperPercent);
        fanController.setSpeed(sr.fanPercent);
    }

    // 4. Fan controller update (kick-start timing, long-pulse cycling)
    fanController.update();

    // 5. Alarm manager
    alarmManager.update(tempManager.getPitTemp(),
                        tempManager.getMeat1Temp(),
                        tempManager.getMeat2Temp(),
                        g_setpoint,
                        g_pitReached);

    // 6. Error manager
    {
        ProbeState probeStates[NUM_PROBES];
        for (uint8_t i = 0; i < NUM_PROBES; i++) {
            ProbeStatus st = tempManager.getStatus(i);
            probeStates[i].connected    = tempManager.isConnected(i);
            probeStates[i].openCircuit  = (st == ProbeStatus::OPEN_CIRCUIT);
            probeStates[i].shortCircuit = (st == ProbeStatus::SHORT_CIRCUIT);
            probeStates[i].temperature  = tempManager.getTemp(i);
        }
        errorManager.update(tempManager.getPitTemp(),
                            fanController.getCurrentSpeedPct(),
                            probeStates);
    }

    // 7. Cook session update (auto-samples and flushes on its own timers)
    cookSession.update();

    // 8. Web server update (broadcasts to WebSocket clients at WS_SEND_INTERVAL)
    webServer.setSetpoint(g_setpoint);
    webServer.update();

    // 9. WiFi manager (handles reconnection)
    wifiManager.update();

    // 10. OTA manager (handles OTA progress)
    otaManager.update();

    // 11. LVGL display update (~1 Hz for data, ~5s for graph)
    if (now - g_lastDisplayMs >= 1000) {
        g_lastDisplayMs = now;

        ui_update_temps(tempManager.getPitTemp(),
                        tempManager.getMeat1Temp(),
                        tempManager.getMeat2Temp(),
                        tempManager.isConnected(PROBE_PIT),
                        tempManager.isConnected(PROBE_MEAT1),
                        tempManager.isConnected(PROBE_MEAT2));

        ui_update_setpoint(g_setpoint);
        ui_update_output_bars(fanController.getCurrentSpeedPct(),
                              servoController.getCurrentPositionPct());

        // Cook timer — starts when first meat probe connects
        if (g_cookStartTime == 0) {
            if (tempManager.isConnected(PROBE_MEAT1) || tempManager.isConnected(PROBE_MEAT2)) {
                g_cookStartTime = (uint32_t)(millis() / 1000);
            }
        }
        {
            uint32_t elapsed = g_cookStartTime > 0
                ? (uint32_t)(millis() / 1000) - g_cookStartTime
                : 0;
            ui_update_cook_timer(0, elapsed, 0);
        }

        // WiFi status
        ui_update_wifi(wifiManager.isConnected() || wifiManager.isAPMode());

        // WiFi info on settings screen
        {
            static String ssidStr, ipStr;
            ssidStr = wifiManager.getSSID();
            ipStr = wifiManager.getIPAddress();
            WifiInfo winfo;
            winfo.connected = wifiManager.isConnected();
            winfo.apMode = wifiManager.isAPMode();
            winfo.ssid = ssidStr.c_str();
            winfo.ip = ipStr.c_str();
            winfo.rssi = wifiManager.getRSSI();
            ui_update_wifi_info(winfo);
        }

        // Alerts
        AlarmType activeAlarms[MAX_ACTIVE_ALARMS];
        uint8_t alarmCount = alarmManager.getActiveAlarms(activeAlarms, MAX_ACTIVE_ALARMS);
        uint8_t topAlarm = 0;
        for (uint8_t i = 0; i < alarmCount; i++) {
            topAlarm = (uint8_t)activeAlarms[i];
            break; // Take the first active alarm
        }
        uint8_t probeErrors = 0;
        if (tempManager.getStatus(PROBE_PIT) != ProbeStatus::OK)   probeErrors |= 0x01;
        if (tempManager.getStatus(PROBE_MEAT1) != ProbeStatus::OK) probeErrors |= 0x02;
        if (tempManager.getStatus(PROBE_MEAT2) != ProbeStatus::OK) probeErrors |= 0x04;
        ui_update_alerts(topAlarm, pidController.isLidOpen(), errorManager.isFireOut(), probeErrors);

        // Meat targets
        ui_update_meat1_target(alarmManager.getMeat1Target());
        ui_update_meat2_target(alarmManager.getMeat2Target());
    }

    // Graph update (every 5 seconds)
    if (now - g_lastGraphMs >= 5000) {
        g_lastGraphMs = now;
        ui_graph_add_point(tempManager.getPitTemp(),
                           tempManager.getMeat1Temp(),
                           tempManager.getMeat2Temp(),
                           g_setpoint,
                           !tempManager.isConnected(PROBE_PIT),
                           !tempManager.isConnected(PROBE_MEAT1),
                           !tempManager.isConnected(PROBE_MEAT2));
    }

    // 12. LVGL tick and task handler
    ui_tick(10);
    ui_handler();

    // Yield to FreeRTOS / keep loop at ~100 Hz
    delay(10);
}

#endif // NATIVE_BUILD

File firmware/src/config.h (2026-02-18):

#pragma once

// --- Pin Assignments (WT32-SC01 Plus Extension Connector) ---
#define PIN_SDA         10
#define PIN_SCL         11
#define PIN_FAN_PWM     12
#define PIN_SERVO       13
#define PIN_BUZZER      14
#define PIN_SPARE       21

// --- ADC Channels (ADS1115) ---
#define ADC_CHANNEL_PIT   0
#define ADC_CHANNEL_MEAT1 1
#define ADC_CHANNEL_MEAT2 2
#define ADC_CHANNEL_SPARE 3

// --- ADS1115 ---
#define ADS1115_ADDR    0x48
#ifndef NATIVE_BUILD
#define ADS1115_GAIN    GAIN_ONE    // +/- 4.096V range
#endif

// --- Voltage Divider ---
#define REFERENCE_RESISTANCE  10000.0   // 10K ohm reference resistor
#define ADC_MAX_VOLTAGE       4.096     // ADS1115 at GAIN_ONE
#define ADC_MAX_VALUE         32767     // 16-bit signed

// --- Steinhart-Hart Coefficients (Thermoworks Pro-Series) ---
#define THERM_A  7.3431401e-04
#define THERM_B  2.1574370e-04
#define THERM_C  9.5156860e-08

// --- PID Defaults ---
#define PID_KP          4.0
#define PID_KI          0.02
#define PID_KD          5.0
#define PID_SAMPLE_MS   4000    // Compute every 4 seconds
#define PID_OUTPUT_MIN  0.0
#define PID_OUTPUT_MAX  100.0

// --- Fan Control ---
#define FAN_PWM_FREQ       25000   // 25 kHz
#define FAN_PWM_CHANNEL    0
#define FAN_PWM_RESOLUTION 8       // 8-bit (0-255)
#define FAN_KICKSTART_PCT  75      // Kick-start at 75%
#define FAN_KICKSTART_MS   500     // for 500ms
#define FAN_MIN_SPEED      15      // Minimum sustained speed %
#define FAN_LONGPULSE_THRESHOLD 10 // Below 10%, use long-pulse mode
#define FAN_LONGPULSE_CYCLE_MS 10000 // 10-second cycle

// --- Servo (Damper) ---
#define SERVO_MIN_US    544     // 0 degrees
#define SERVO_MAX_US    2400    // 180 degrees
#define DAMPER_CLOSED   0       // Servo angle for closed
#define DAMPER_OPEN     90      // Servo angle for full open

// --- Split-Range Fan+Damper ---
#define FAN_ON_THRESHOLD   30   // Default fan-on threshold (runtime value from configManager)

// --- Temperature Reading ---
#define TEMP_SAMPLE_INTERVAL_MS  1000   // Read probes every 1 second
#define TEMP_AVG_SAMPLES         4      // Average 4 readings
#define TEMP_EMA_ALPHA           0.2    // EMA smoothing factor (lower = smoother, less derivative noise)

// --- Lid-Open Detection ---
#define LID_OPEN_DROP_PCT   6    // 6% drop below setpoint triggers lid-open
#define LID_OPEN_RECOVER_PCT 2   // Recovered when within 2% of setpoint

// --- Cook Session ---
#define SESSION_BUFFER_SIZE     600     // RAM buffer samples
#define SESSION_SAMPLE_INTERVAL 5000    // 5 seconds between data points
#define SESSION_FLUSH_INTERVAL  60000   // Flush to LittleFS every 60 seconds
#define SESSION_FILE_PATH       "/session.dat"

// --- Config ---
#define CONFIG_FILE_PATH  "/config.json"

// --- Web Server ---
#define WEB_PORT          80
#define WS_PATH           "/ws"
#define WS_MAX_CLIENTS    4
#define WS_SEND_INTERVAL  1500   // Send data every 1.5 seconds

// --- Alarms ---
#define ALARM_PIT_BAND_DEFAULT  15.0    // +/- 15F
#define ALARM_BUZZER_FREQ       2000    // 2kHz tone
#define ALARM_BUZZER_DURATION   500     // 500ms beep
#define ALARM_BUZZER_PAUSE      500     // 500ms pause between beeps

// --- Error Detection ---
#define ERROR_PROBE_OPEN_THRESHOLD   32000  // ADC value indicating open circuit
#define ERROR_PROBE_SHORT_THRESHOLD  100    // ADC value indicating short
#define ERROR_FIREOUT_RATE           2.0    // Degrees F per minute decline
#define ERROR_FIREOUT_DURATION_MS    600000 // 10 minutes of decline

// --- Display ---
#define DISPLAY_WIDTH   480
#define DISPLAY_HEIGHT  320

// --- Misc ---
#define WIFI_HOSTNAME       "bbq"
#define MDNS_HOSTNAME       "bbq"
#define AP_SSID             "BBQ-Setup"
#define AP_PASSWORD         "bbqsetup"
#ifndef FIRMWARE_VERSION
#define FIRMWARE_VERSION    "dev"
#endif

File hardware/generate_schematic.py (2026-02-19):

#!/usr/bin/env python3
"""Generate KiCad 8 schematic for the Pit Claw BBQ Controller carrier board.

Run: python hardware/generate_schematic.py
Output: hardware/bbq-controller.kicad_sch

Every wire endpoint is computed from symbol pin definitions so connections
are guaranteed to match. Re-run after editing positions or topology.
"""

import uuid
import os

def uid():
    return str(uuid.uuid4())


# ---------------------------------------------------------------------------
# KiCad coordinate helpers
# ---------------------------------------------------------------------------
# Sheet coords: Y increases downward.
# Symbol local coords (in lib_symbols): Y increases upward.
# Pin (at lx ly angle) gives the CONNECTION POINT in local coords.
# Placed at (sx, sy) with rotation 0: sheet_pin = (sx + lx, sy - ly)

def pin_sheet(sx, sy, lx, ly):
    """Convert local pin position to sheet position (no rotation)."""
    return (round(sx + lx, 4), round(sy - ly, 4))


# ---------------------------------------------------------------------------
# Symbol definitions (lib_symbols)
# ---------------------------------------------------------------------------

LIB_SYMBOLS = r"""
  (lib_symbols
    (symbol "Device:R"
      (pin_numbers hide)
      (pin_names (offset 0) hide)
      (exclude_from_sim no)
      (in_bom yes)
      (on_board yes)
      (property "Reference" "R" (at 2.032 0 90) (effects (font (size 1.27 1.27))))
      (property "Value" "R" (at -2.032 0 90) (effects (font (size 1.27 1.27))))
      (property "Footprint" "" (at -1.778 0 90) (effects (font (size 1.27 1.27)) hide))
      (property "Datasheet" "~" (at 0 0 0) (effects (font (size 1.27 1.27)) hide))
      (property "Description" "Resistor" (at 0 0 0) (effects (font (size 1.27 1.27)) hide))
      (symbol "R_0_1"
        (rectangle (start -1.016 -2.54) (end 1.016 2.54)
          (stroke (width 0) (type default))
          (fill (type none))
        )
      )
      (symbol "R_1_1"
        (pin passive line (at 0 3.81 270) (length 1.27)
          (name "~" (effects (font (size 1.27 1.27))))
          (number "1" (effects (font (size 1.27 1.27))))
        )
        (pin passive line (at 0 -3.81 90) (length 1.27)
          (name "~" (effects (font (size 1.27 1.27))))
          (number "2" (effects (font (size 1.27 1.27))))
        )
      )
    )
    (symbol "Device:C"
      (pin_numbers hide)
      (pin_names (offset 0.254) hide)
      (exclude_from_sim no)
      (in_bom yes)
      (on_board yes)
      (property "Reference" "C" (at 2.54 0 90) (effects (font (size 1.27 1.27)) (justify left)))
      (property "Value" "C" (at -2.54 0 90) (effects (font (size 1.27 1.27)) (justify left)))
      (property "Footprint" "" (at 0.9652 -3.81 0) (effects (font (size 1.27 1.27)) hide))
      (property "Datasheet" "~" (at 0 0 0) (effects (font (size 1.27 1.27)) hide))
      (property "Description" "Capacitor" (at 0 0 0) (effects (font (size 1.27 1.27)) hide))
      (symbol "C_0_1"
        (polyline
          (pts (xy -2.032 -0.762) (xy 2.032 -0.762))
          (stroke (width 0.508) (type default))
          (fill (type none))
        )
        (polyline
          (pts (xy -2.032 0.762) (xy 2.032 0.762))
          (stroke (width 0.508) (type default))
          (fill (type none))
        )
      )
      (symbol "C_1_1"
        (pin passive line (at 0 3.81 270) (length 2.794)
          (name "~" (effects (font (size 1.27 1.27))))
          (number "1" (effects (font (size 1.27 1.27))))
        )
        (pin passive line (at 0 -3.81 90) (length 2.794)
          (name "~" (effects (font (size 1.27 1.27))))
          (number "2" (effects (font (size 1.27 1.27))))
        )
      )
    )
    (symbol "Device:Buzzer"
      (pin_names (offset 1.016) hide)
      (exclude_from_sim no)
      (in_bom yes)
      (on_board yes)
      (property "Reference" "BZ" (at 5.08 1.27 0) (effects (font (size 1.27 1.27)) (justify left)))
      (property "Value" "Buzzer" (at 5.08 -1.27 0) (effects (font (size 1.27 1.27)) (justify left)))
      (property "Footprint" "" (at -1.016 -3.556 90) (effects (font (size 1.27 1.27)) hide))
      (property "Datasheet" "~" (at -1.016 -3.556 90) (effects (font (size 1.27 1.27)) hide))
      (property "Description" "Buzzer, polarized" (at 0 0 0) (effects (font (size 1.27 1.27)) hide))
      (symbol "Buzzer_0_1"
        (arc (start -3.302 -2.54) (mid 2.159 0) (end -3.302 2.54)
          (stroke (width 0.254) (type default))
          (fill (type none))
        )
        (polyline
          (pts (xy -3.302 2.54) (xy -3.302 -2.54))
          (stroke (width 0.254) (type default))
          (fill (type none))
        )
        (text "+" (at -3.81 3.175 0) (effects (font (size 1.27 1.27))))
      )
      (symbol "Buzzer_1_1"
        (pin passive line (at 0 5.08 270) (length 2.54)
          (name "+" (effects (font (size 1.27 1.27))))
          (number "1" (effects (font (size 1.27 1.27))))
        )
        (pin passive line (at 0 -5.08 90) (length 2.54)
          (name "-" (effects (font (size 1.27 1.27))))
          (number "2" (effects (font (size 1.27 1.27))))
        )
      )
    )
    (symbol "bbq:IRLZ44N"
      (pin_names (offset 1.016))
      (exclude_from_sim no)
      (in_bom yes)
      (on_board yes)
      (property "Reference" "Q" (at 7.62 1.27 0) (effects (font (size 1.27 1.27)) (justify left)))
      (property "Value" "IRLZ44N" (at 7.62 -1.27 0) (effects (font (size 1.27 1.27)) (justify left)))
      (property "Footprint" "Package_TO_SOT_THT:TO-220-3_Vertical" (at 0 0 0) (effects (font (size 1.27 1.27)) hide))
      (property "Datasheet" "" (at 0 0 0) (effects (font (size 1.27 1.27)) hide))
      (property "Description" "N-channel logic-level MOSFET, TO-220" (at 0 0 0) (effects (font (size 1.27 1.27)) hide))
      (symbol "IRLZ44N_0_1"
        (polyline
          (pts (xy -2.54 -2.54) (xy -2.54 2.54))
          (stroke (width 0.254) (type default))
          (fill (type none))
        )
        (polyline
          (pts (xy -1.27 2.54) (xy -1.27 -2.54))
          (stroke (width 0.508) (type default))
          (fill (type none))
        )
        (polyline
          (pts (xy -1.27 -1.905) (xy 2.54 -1.905) (xy 2.54 -2.54))
          (stroke (width 0.254) (type default))
          (fill (type none))
        )
        (polyline
          (pts (xy -1.27 1.905) (xy 2.54 1.905) (xy 2.54 2.54))
          (stroke (width 0.254) (type default))
          (fill (type none))
        )
        (polyline
          (pts (xy -1.27 0) (xy 2.54 0))
          (stroke (width 0.254) (type default))
          (fill (type none))
        )
        (polyline
          (pts (xy 2.54 0) (xy 0.762 0.762) (xy 0.762 -0.762) (xy 2.54 0))
          (stroke (width 0.254) (type default))
          (fill (type outline))
        )
        (text "D" (at 3.81 -2.54 0) (effects (font (size 0.762 0.762))))
        (text "G" (at -3.81 0 0) (effects (font (size 0.762 0.762))))
        (text "S" (at 3.81 2.54 0) (effects (font (size 0.762 0.762))))
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

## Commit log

2026-02-12 Add session persistence and fix simulator speed passthrough
    - Server sends session history to new WebSocket clients on connect,
    so browser refresh preserves chart data and state
    - Client handles 'history' message to bulk-load chart, targets, and
    cook timer from server-side session data
    - Simulator persists session + thermal model state to session.dat,
    surviving nodemon restarts
    - Read SPEED/PROFILE from env vars so `SPEED=50 npm run dev` works
    (concurrently was swallowing CLI args passed via --)
    - Add browser-sync --ws flag to proxy WebSocket connections
    - Add simulator/session.dat to .gitignore
2026-02-12 Migrate from deprecated AsyncElegantOTA to ElegantOTA v3 async mode
    AsyncElegantOTA has been removed from the PlatformIO registry.
    ElegantOTA v3 with ELEGANTOTA_USE_ASYNC_WEBSERVER=1 is the replacement.
    [ota_manager.cpp]
2026-02-13 Add Pit Claw web UI screenshot to README
2026-02-13 Update repo references from bbq to open-claw
    Update CI badge URLs, clone URL, and directory name in README to
    match the renamed GitHub repository.
2026-02-13 Rename repo references to pit-claw
2026-02-18 Add embedded web server to simulator, shared protocol layer, and OTA firmware updates
    Replaces the Node.js simulator web server with an embedded mongoose HTTP+WebSocket
    server running in the same process as the SDL2 touchscreen UI. Extracts WebSocket
    message building/parsing into a shared protocol layer (web_protocol.h/cpp) used by
    both firmware and simulator — one source of truth.
    Key additions:
    - Mongoose-based web server in simulator serving firmware/data/ files
    - Shared WebSocket protocol abstraction (DataPayload, HistoryPoint, ParsedCommand)
    - OTA firmware update flow in web UI (GitHub release check, download, chunked upload)
    - Adaptive graph history buffer (240-point with pairwise c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
    [config.h, main.cpp, pid_controller.cpp]
2026-02-18 Replace hand-drawn SVG with KiCad schematic project
    Industry-standard EDA format with proper symbols, net labels, and
    component references. Includes custom symbols for MP1584EN and ADS1115
    breakout modules. All inter-section connections use named nets for
    clarity. Open with KiCad 8 (free) to view, edit, and export to PDF/SVG.
    [bbq-controller.kicad_sch]
2026-02-19 Fix KiCad schematic wiring and add perfboard layout to assembly guide
    Rewrote the KiCad schematic using a Python generator script that computes
    exact pin-to-wire coordinates, fixing all disconnected components. Added a
    detailed perfboard layout section to the assembly guide showing component
    placement on the 50x70mm board with grid references and back-side wiring
    instructions.
    [bbq-controller.kicad_sch]
2026-02-19 Update /feature and /ship lifecycle commands (#13)
    ## Summary
    - `/feature` now implements the feature directly after creating the spec
    and worktree, then offers to `/ship` — no manual terminal switching
    needed
    - `/ship` now waits for CI checks and merge completion, then
    automatically cleans up the worktree
    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
2026-02-19 Restructure README and split developer docs (#18)
    - Streamlined README to focus on builder onboarding: project intro,
    hardware BOM, and a 5-step getting started guide
    - Moved wiring diagram, simulator docs, testing, architecture, and
    WebSocket protocol into dedicated guides in `docs/`
    - Added development index table in README linking to all guides
    - Restored `node_modules/` to `.gitignore` (accidentally removed in
    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
2026-02-19 Add /setup command for GitHub repo best practices (#19)
    - Adds a `/setup` Claude Code slash command that configures the GitHub
    repo with best practices for a solo developer
    - Audits current repo state, shows a summary of proposed changes, asks
    for confirmation, then executes all configuration via `gh` CLI and file
    creation
    - Configures: branch protection (CI required, linear history, no PR
    reviews), repo topics, Dependabot, issue/PR templates, security policy,
    and 8 project-specific labels
    - Designed to be run once per repo, idempotent where possible
    ## Test plan
    - [x] `.claude/commands/setup.md` exists and is well-formed
    - [x] Command includes `allowed-tools` frontmatter with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
2026-02-19 Fix simulator pit temp stuck below setpoint (#24)
    - Simulator pit temperature was stuck at ~216-217°F instead of
    converging to the 225°F setpoint
    - Root cause: `maxAchievable` was multiplied by instantaneous airflow,
    which dropped when the PID backed off near setpoint — a self-defeating
    feedback loop
    - Fix: `fireEnergy` now responds to airflow over time (oxygen
    replenishes coals, natural decay consumes fuel) and `maxAchievable` uses
    only `fireEnergy`, giving the charcoal fire realistic thermal mass
    - At steady state, moderate PID output sustains fire energy near 1.0,
    keeping `maxAchievable` at ~400°F (well above any setpoint)
    - [x] Simulator builds: `pio run -e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
2026-02-19 Add device and web UI screenshots to README (#25)
    - Split README hero area into two sections: **Touchscreen Dashboard**
    and **Web Interface**
    - Added device touchscreen screenshot (`pitclaw-device.png`)
    - Updated web UI screenshot (`pitclaw.png`)
    - Each section has a heading and short description for a cleaner, more
    professional layout
    - [x] README renders correctly on GitHub with both image references
    - [x] Placeholder filename `pitclaw-device.png` is referenced correctly
    - [x] Existing `pitclaw.png` reference is preserved
    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
2026-02-19 Wire setup wizard into boot flow with boot splash (#27)
    - Boot splash screen shows immediately after config load, visible during
    WiFi and hardware init
    - 10-second touchscreen hold on splash triggers factory reset (with
    progress bar and color-changing hint text)
    - Setup wizard runs automatically on first boot when `setupComplete ==
    false`
    - Non-blocking hardware test callbacks keep LVGL responsive during
    wizard fan/servo/buzzer tests
    - Splash screen LVGL objects cleaned up after transition to free ESP32
    memory
    - Simulator persists setup state to `.sim_setup_complete` file — wizard
    runs on first launch, skips on subsequent launches
    - Simulator factory reset (from settings screen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
    [main.cpp]
